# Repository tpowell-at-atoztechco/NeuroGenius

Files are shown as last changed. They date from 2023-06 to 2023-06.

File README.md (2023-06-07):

     _   _                       ____            _           
    | \ | | ___ _   _ _ __ ___  / ___| ___ _ __ (_)_   _ ___ 
    |  \| |/ _ \ | | | '__/ _ \| |  _ / _ \ '_ \| | | | / __|
    | |\  |  __/ |_| | | | (_) | |_| |  __/ | | | | |_| \__ \
    |_| \_|\___|\__,_|_|  \___/ \____|\___|_| |_|_|\__,_|___/
 
NeuroGenius - Open source, MRI imaging hardware and software (Using readily-accessible parts and operating systems, all published and documented.)

Our goal: Increasing the oligodendrocyte cell population and performi targeted remyelination through real-time functional MRI analysis for neurofeedback. Primarily as a treatment to restore functionality 
in multiple sclerosis patients and patients with other neurodegenerative diseases.

Primary Endpoints:

    1.) Providing real-time fMRI analysis using fully reproducable open source hardware and software.
    2.) Stimulated Oligodendrocyte cell population growth through secondary neurofeedback stimulation.
    3.) Successful remyeliniation on patients which can be witnessed in professional gadolinium-enhanced MRI imaging, which is universally reproducable.
    
Secondary Endpoints:

    1.) Decreased levels of cNfL levels in blood tests.
    2.) Increased evidence of oligodendrocyte stimulation in blood testing should be conducive to a strong remylenation environment.

<h1>Credits</h1>
<p>NeuroGenius is built entirely using open-source designs, including the OSI² ONE MR imager and the Homemade Liquid Nitrogen Generator.</p>
<p>Original MR Imaging design by OpenSourceImaging.org's OSI² ONE (https://www.opensourceimaging.org/2023/01/09/first-open-source-mri-scanner-presented-the-osii-one/), and is based off of their hardware designs for MRI imaging. Upgrades to their design are underway, and will be posted as they become available. For the moment, it gives us the ability to perform real-time MRI analysis, albeit somewhat low quality. Our goal is to build the technology from this point, and provide detailed documentation on how to build the MRI machine, operate the hardware and software, and build your own projects on top of it.</p>
<h1>Sitemap</h1>
<p>Helps you navigate the NeuroGenius project files. We've done our best to layout the project as best as we can, but this point of reference makes it even more user-friendly.</p>
<ul>
<li><b>Folders (/)</b>:
<ul>
<li><p><b>Concept</b>: GitHub-formatted references and guides to magnetic resonance imaging science and terminilogy, including a step-by-step guide to assemble your very own MRI machine and a liquid nitrogen generator from scratch.</p></li>
<li><p><b>Hardware</b>: Contains 3D models and circuit diagrams for building both the MRI machine and DIY Cryogenic Electrolysis system for Hydrogen Purification and Liquification.</p></li>
<li><p><b>Software</b>: Contains software for the MRI machine, which will include code for the RF amplifier, gradient power amplifier, the software to actually deliver the MRI data from raw magnetic resonance input, and the Slicer software to run comparative analysis. </p><p>Eventually, this will include a folder for NeuroGenius, which will be available as a Windows app, Apple Mac & iOS app, Android app, and a Linux app.</p>
</ul>
</li>
<li><b>Files (/)</b>:
<ul>
<li><p><b>README.md</b>: This README file</p></li>
</ul>
</li>
</ul>

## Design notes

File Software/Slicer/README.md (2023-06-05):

<h1>3D Slicer</h1>
<h2>Image computing platform</h2>
<p>3D Slicer is an open-source application designed to open and interpret MRI data, allowing you to apply patterns and create your own database of MRI files. Upon installation, one of the first things you'll see is that it's not, "designed for clinical use." With that said, it is incorporated into many similiar softwares used professionally and internationally</p><p>3D SLicer can be downloaded from <a href="https://download.slicer.org/">https://download.slicer.org/</a> for Windows, Mac OS, and Linux, completely free of charge.</p><p>For compatibility purposes, we're including a copy of the SLicer installer in this repository. All of these are current as of June 5th, 2023.</p>
<p>Slicer is built and tested on many hardware and software platforms. 3D Slicer runs on modern Windows, macOS, and a variety of Linux distributions.<p>
<h3>Operating System</h3>
<ul>
<li>Windows: Windows 10 or 11, with all recommended updates installed. Windows 10 Version 1903 (May 2019 Update) version or later is required for support of international characters (UTF-8) in filenames and text. Microsoft does not support Windows 8.1 and Windows 7 anymore and Slicer is not tested on these legacy operating system versions, but may still work.</li>
<li>macOS: macOS Big Sur (11) or later (both Intel and ARM based systems). Latest public release is recommended.</li>
<li>Linux: Ubuntu 18.04 or later<br/>
CentOS 7 or later. Latest LTS (Long-term-support) version is recommended.</li>
</ul>
<h3>Hardware</h3>
<ul>
<li>Memory: more than 4GB (8 or more is recommended). As a general rule, have 10x more memory than the amount of data that you load.</li>
<li>Display: a minimum resolution of 1024 by 768 (1280 by 1024 or better is recommended).</li>
<li>Graphics: Dedicated graphics hardware (discrete GPU) memory is recommended for fast volume rendering. GPU: Graphics must support minimum OpenGL 3.2. Integrated graphics card is sufficient for basic visualization. Discrete graphics card (such as NVidia GPU) is recommended for interactive 3D volume rendering and fast rendering of complex scenes. GPU texture memory (VRAM) should be larger than your largest dataset (e.g., working with 2GB data, get VRAM > 4GB) and check that your images fit in maximum texture dimensions of your GPU hardware. Except rendering, most calculations are performed on CPU, therefore having a faster GPU will generally not impact the overall speed of the application.</li>
<li>Some computations in 3D Slicer are multi-threaded and will benefit from multi core, multi CPU configurations.</li>
<li>Interface device: a three button mouse with scroll wheel is recommended. Pen, multi-touchscreen, touchpad, and graphic tablet are supported. All OpenVR-compatible virtual reality headsets are supported for virtual reality display.</li>
<li>Internet connection to access extensions, Python packages, online documentation, sample data sets, and tutorials.</li>
</ul>

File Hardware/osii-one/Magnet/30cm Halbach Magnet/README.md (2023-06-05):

# Permanent magnet in Halbach arrangement

Permanent magnet(B<sub>0</sub> around 48mT) MRI system. 

## System specifications
- Permanent magnet (~4000x (12x12x12)mm³ NdFeB magnets in Halbach arrangement)
- B<sub>0</sub> = 48mT
- Homogeneity (25cm, before shim) = 17.000 ppm
- Homogeneity (20cm, before shim) = 7.000 ppm
- Weight ~100kg

## Authors and acknowledgment
Design by Lukas Winter (lukas.winter@ptb.de) on the basis of O'Reilly T, et al., ISMRM 2022, #0063.
The number of magnets and radius was determined by using the open source software: https://github.com/LUMC-LowFieldMRI/HalbachOptimisation

If you find this work useful, please cite: 
O'Reilly T, Teeuwisse WU, Webb A, Three-Dimensional MRI in a homogeneous 27cm diameter Bore Halbach Array Magnet, J Magn Reson, 2019, 307:106578

O'Reilly T, Teeuwisse W, Webb A, A New Approach to Shimming Halbach Arrays Using Higher Order Halbach Array Inserts, ISMRM 2022, #0063

## License and Liability
This is an open source hardware project licensed under the CERN Open Hardware license. For more information please check the [DISCLAIMER.pdf](DISCLAIMER.pdf).

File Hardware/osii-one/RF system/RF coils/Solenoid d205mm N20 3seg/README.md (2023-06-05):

# Solenoid RF coil - 20.5cm, f=2.04Mhz

A multipurpose RF coil for low-field MRI of the OSI² ONE system. Designed to image the ACR phantom. 

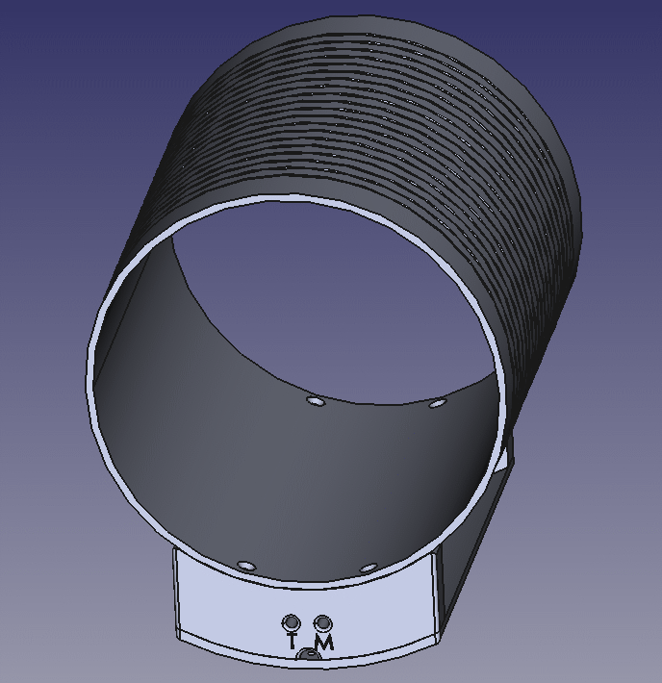
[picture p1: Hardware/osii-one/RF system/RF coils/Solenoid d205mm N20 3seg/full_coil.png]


## Specifications
- Inner diameter: 205mm
- Outer diamter: 213mm
- Solenoid length: 200mm
- Housing length: 240mm
- Number of turns: 20
- Number of segmentations: 3

## Authors and contributors

Original design by Tom O'Reilly (t.o_reilly@lumc.nl), LUMC, Leiden, Netherlands.

## (Known) builds
Name | Email | Institution 
|-----|-----|-----|
Tom O'Reilly | t.o_reilly@lumc.nl | LUMC, Leiden, Netherlands 
Lukas Winter | lukas.winter@ptb.de | Physikalisch-Technische Bundesanstalt (PTB), Berlin, Germany

## License and Liability
Please check the [DISCLAIMER.pdf](DISCLAIMER.pdf).

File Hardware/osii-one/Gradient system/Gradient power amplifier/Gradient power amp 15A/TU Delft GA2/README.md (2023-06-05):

# TU Delft GA2

Three-channel gradient power amplifier designed for a low-field (B<sub>0</sub> around 50mT) MRI system. For more information on the design, please check the [GA_DesignDoc.pdf](GA_DesignDoc.pdf).

## System specifications
- I<sub>LOAD</sub> = &#177;15A
- Duty cycle: 30% per channel
- Potentially battery powered
- V<sub>in</sub>=&#177;10V
- L=20&micro;H - 300 &micro;H (180 &micro;H)
- ESR = 0.4&ohm;, C<sub>PAR</sub> = 130 &pico;F
- t<sub>r</sub>=50 &micro;s, B=7kHz
- R<sub>SOURCE</sub>=200&ohm;
- Overload protection
- Low noise current and EMI especially between 0.5MHz...5MHz

## Authors and acknowledgment
Original design by Danny de Gans (D.H.deGans@tudelft.nl) from TU Delft, Netherlands.

## License and Liability
Please check the [DISCLAIMER.pdf](DISCLAIMER.pdf).

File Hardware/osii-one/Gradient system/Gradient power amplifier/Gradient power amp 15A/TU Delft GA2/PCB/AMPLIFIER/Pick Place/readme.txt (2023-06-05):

Instructions for assembly at Eurocircuits

Upload the zip file with the gerber files
After it has been verified open the PCB visualizer to view the PCB
Check the box "Include assembly" and select the PCBA visualizer tab
Press the button edit assembly data and Upload the BOM (Bill Of Materials)
Set the column information correctly:
Data header row:	1
Data start from row:	2
Data ends at row:	59
label the columns correctly:
Quantity, Designator and manufacturer part number
All other columns can be set to "None"

After that some components might not be recognized or should not be assembled.
Always use the exact part numbers in the search field at the bottom of the online tool
to find the correct parts. The Trough Hole transistors/FETs that are mounted onto
the heatsink should be soldered afterwards during final assembly
P2,5,8	TH	are 2 separate parts to order. MSTB2.5HC/2-GF (1923979) is the part to be selected. 1912074 is the counter part
C26,29,59,62,92,95	Do Not Assemble	, mark as Not placed in the "Supplied by:" field
R58,129,200	Do Not Assemble	, mark as Not placed in the "Supplied by:" field
Q88	Should first be mounted onto the heatsink before soldering. Mark as Not placed in the "Supplied by:" field
Q10,25,60	Should first be mounted onto the heatsink before soldering. Mark as Not placed in the "Supplied by:" field
Q13,38,63	Should first be mounted onto the heatsink before soldering. Mark as Not placed in the "Supplied by:" field
Q93	Should first be mounted onto the heatsink before soldering. Mark as Not placed in the "Supplied by:" field and "ignored"

In the manufacturers ordering process resistors and capacitors might be replaced
by "regular"parts. This is not advisable for the precise parts !!!!!!

Select the CPL tab
Upload the CPL (Component Placement List) pick and place file "EC_PickAndPlace.txt"
This file has some modified orientations to match the Eurocircuits process
delimiter:	space
data header row:	13
data start from row:	14
data ends at row:	555
The reference designator, side, center x, center y and rotation must be indentified manually
All other columns can be set to "None"
After submitting some parts need to be shifted by using the online tool "Offset Component":
P10,11,12,13
Q87,89,92,94

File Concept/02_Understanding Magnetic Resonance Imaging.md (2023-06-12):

Basic Principles of Magnetic Resonance Imaging:
Magnetic Resonance Imaging (MRI) is a non-invasive imaging technique that uses a powerful magnetic field and radio waves to generate detailed images of the body's internal structures. It is especially useful for imaging soft tissues and organs like the brain. The basic principle behind MRI involves aligning the spins of hydrogen atoms in the body using a strong magnetic field, then disturbing this alignment with a radiofrequency pulse. The subsequent relaxation of these atoms produces signals that are captured and processed to create images.

Components of an MRI Machine:
A typical MRI machine comprises of several key components: the main magnet that creates a powerful magnetic field, gradient coils that generate smaller magnetic fields for spatial encoding, a radiofrequency (RF) system that sends and receives signals, and a computer system to control these components and process the acquired data. These elements work together to create a detailed image of the desired section of the body.

Functionality of an MRI Machine:
The MRI machine works by first creating a strong magnetic field that aligns the protons in the body. The RF system then sends a radio wave to disturb this alignment. As the protons return to their original state, they emit signals that the RF system detects. These signals are processed by the computer system to create a detailed image. Different tissue types return to their original state at different rates, allowing for differentiation between them in the final image.

Understanding MRI Signals and Image Processing:
The signals received in an MRI machine are known as Free Induction Decay (FID) signals, which are then digitized and processed. Fourier transform, a mathematical technique, is used to convert these time-domain signals into frequency-domain data, allowing the spatial location of the signal source (tissue) to be determined. This is the basis for image formation in MRI.

Introduction to MRI-Driven Neurofeedback:
MRI-driven neurofeedback is a process where individuals can view and potentially alter their brain activity in real-time. By integrating this feature into the NeuroGenius software, users can gain insights into their neural activities and even attempt to modify them. This unique capability offers opportunities for self-exploration, potential therapeutic uses, and advancement in neuroscience research.

Safety Concerns in Magnetic Resonance Imaging:
Despite being a non-invasive technique, MRI involves the use of strong magnetic fields and radio waves, which necessitate certain safety precautions. These include excluding individuals with certain implants or metallic objects from undergoing an MRI scan, and ensuring that the machine is operated properly to avoid any potential harm. Safety guidelines provided by NeuroGenius and other professional bodies should always be followed.

Exploring the Future: Personal MRI with NeuroGenius:
NeuroGenius offers the intriguing possibility of personal, open-source MRI technology. By enabling individuals to build, modify, and improve upon their own MRI machine and accompanying software, NeuroGenius empowers users to explore the fascinating world of neuroimaging. This not only democratizes the technology but also spurs innovation and research in the field, paving the way for advancements in understanding the human brain.

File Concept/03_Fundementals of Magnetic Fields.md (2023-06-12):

The Physics of Magnetic Fields:
Magnetic fields are vector fields that exert forces on magnetic dipoles, such as atoms or subatomic particles like electrons and protons. The intensity and direction of these fields, measured in units of Tesla (T) in the International System of Units, can significantly influence the behavior of these particles, and this property is the basis of MRI technology.

Role of Magnetic Fields in MRI: Nuclear Magnetic Resonance:
Magnetic Resonance Imaging leverages the physics of nuclear magnetic resonance (NMR). In the presence of an external magnetic field, atomic nuclei such as hydrogen (the most abundant in the human body) exhibit magnetic properties because of their spin. The external field causes these protons to align along the direction of the field, creating two energy states. When an additional radio frequency (RF) pulse, tuned to the resonance frequency of these protons, is introduced, the protons absorb the RF energy and flip to the higher energy state. When the RF pulse is turned off, the protons relax back to their lower energy state, emitting a signal in the process. This emitted signal forms the basis of the MRI image.

Generation and Control of Magnetic Fields in MRI Systems:
MRI machines typically generate magnetic fields using superconducting coils, often composed of niobium-titanium alloy, which are cooled to cryogenic temperatures with liquid helium. The use of superconducting materials allows for high current density and thus high magnetic fields to be produced, with excellent temporal stability. Fine control of these magnetic fields is essential for accurate imaging and is accomplished through a combination of hardware design and software control.

The Impact of Magnetic Field Homogeneity and Strength on Image Quality:
The quality and clarity of an MRI image depend on the strength and homogeneity of the magnetic field. A stronger magnetic field leads to a higher signal-to-noise ratio, which improves the resolution and quality of the image. Homogeneity of the field is crucial to ensure consistent signal generation across the imaging volume, which is achieved through a process called shimming. However, higher magnetic field strengths introduce additional technical challenges and safety considerations.

Magnetic Field Gradients and Spatial Encoding:
Gradient magnetic fields are used in MRI to spatially encode the source of the NMR signals. These gradients are superimposed on the main static magnetic field, and they allow the MRI machine to localize the signal in three dimensions. This spatial encoding forms the basis for the construction of detailed, slice-by-slice images of the body's internal structures.

Biophysical Safety Considerations of MRI Magnetic Fields:
The strong magnetic fields and rapid gradient switching in MRI can have significant safety implications. The static magnetic field can attract ferromagnetic materials, leading to potential projectile hazards. Rapid switching of gradient fields can induce electrical currents in the body, causing peripheral nerve stimulation. Care must be taken to ensure that the specific absorption rate (SAR) of RF energy is within safe limits to prevent tissue heating.

Tailoring Magnetic Fields for NeuroGenius: Engineering and Design:
NeuroGenius presents unique challenges and opportunities in the design and control of magnetic fields for personal MRI use. Open-source collaboration allows for continuous innovation in creating effective magnetic field control strategies, improving homogeneity, increasing field strength, and managing safety issues. As a user-based MRI project, NeuroGenius propels further understanding and advancements in the generation and manipulation of magnetic fields for MRI applications.

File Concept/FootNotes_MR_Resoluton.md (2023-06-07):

<h1>Resolution in MR Imaging (In Common Terms)</h1>
<p>MRI resolution is typically measured in units of millimeters (mm) or micrometers (μm). It refers to the level of detail or the smallest discernible feature that can be distinguished in an MRI image.</p>
<p>In comparison to photography, where resolution is commonly expressed in terms of pixels, megapixels (MP), and gigapixels (GP), there is a fundamental difference in how resolution is quantified in MRI and digital imaging.</p>
<p>In MRI, resolution is primarily determined by the physical characteristics of the imaging system, such as the strength of the magnetic field, gradient strength, and the specific imaging sequence used. It is influenced by factors like voxel size, signal-to-noise ratio, and the inherent limitations of the MRI technology itself. The resolution is typically specified in terms of the smallest distinguishable feature size, such as the smallest anatomical structure or lesion that can be resolved.</p>
<p>On the other hand, in digital photography, resolution refers to the number of pixels in an image, often represented as megapixels (1 MP = 1 million pixels) or gigapixels (1 GP = 1 billion pixels). It represents the total number of individual picture elements that make up the image. Higher pixel counts generally allow for greater detail and the ability to enlarge or crop images without significant loss of quality.</p>
<p>It's important to note that the concept of resolution in MRI and digital imaging is not directly comparable. MRI resolution is not directly measured in pixels, as it is based on the physical properties of the imaging system and the ability to resolve fine details in the scanned anatomy. In contrast, digital imaging resolution, such as in photography, is determined by the number of pixels captured and displayed in the image.</p>
<h2>Interference and pinpoint accuracy in MR systems</h2>
<p>When it comes to MRI systems, the magnetic field strength plays a crucial role in determining the resolution and image quality. Low-field MRI systems typically operate at magnetic field strengths below 1.5 Tesla, while high-field MRI systems utilize stronger magnetic fields, often ranging from 1.5 Tesla to 3 Tesla or even higher.</p>
<p>The use of expensive magnets and superconductors in high-field MRI systems allows for the generation of a higher magnetic field, resulting in improved image resolution and quality. The higher field strength enhances the signal-to-noise ratio, enabling clearer visualization of anatomical structures and smaller pathological features.</p>
<p>With higher field strength, the pinpoint accuracy of imaging is enhanced, allowing for more precise localization and characterization of abnormalities. This can be particularly beneficial in areas such as neuroimaging, where fine details and small lesions need to be accurately identified.</p>
<p>However, it's worth noting that high-field MRI systems require specialized infrastructure, including proper shielding and cooling systems for the superconducting magnets, which can be more costly to install and maintain compared to low-field systems.</p>
<p>Overall, the choice between low-field and high-field MRI systems depends on various factors, including the specific imaging requirements, available resources, and the desired level of resolution and image quality for a particular clinical or research application.</p>
<h2>Incorporating MRI Imaging with Superconductivity</h2>
<p>One of the major barriers in producing a high-field magnetic resonance imaging machine is the cost associated with acquiring magnets that can generate a high magnetic field. Low magnetic fields product unit while high magnetic fields product unit. Run-of-the-mill rare earth magnets product

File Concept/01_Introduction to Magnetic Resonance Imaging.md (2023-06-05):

This introduction is intended to be easy to build, despite being remarkably complex in design and it's very nature. In this section, we'll attempt 
to break down what an MRI machine is, how it's used, and how it functionaly operates to capture imagery that's otherwise unobtainable. We'll also
delve into the different types of MRI machines, and dissect the exact hardware and software differences.

<h1>Concept: What is an MRI machine? (In simple terms)</h1>

An <i>MRI machine</i> is a special machine that helps doctors see inside your body to find out what's happening. It's like taking a picture, but instead 
of using light, it uses strong magnets and radio waves.

When you go inside the MRI machine, you lie down on a table that moves into a big tube-like machine. The machine has a very strong magnet inside, 
like a giant magnet. This magnet creates a powerful magnetic field around you.

Our bodies have lots of tiny particles called atoms. One of the most common atoms in our body is called hydrogen. The magnet in the MRI machine
makes the hydrogen atoms in your body act in a special way, rotating so that the MRI machine can see them.

Next, the machine sends radio waves into your body. These radio waves make the hydrogen atoms in your body vibrate. When the radio waves stop,
the hydrogen atoms go back to their normal state.

But here's the cool part: when the hydrogen atoms go back to their normal state, they release a signal. This signal is like a message that the MRI
machine can understand. The machine captures these signals and turns them into pictures.

These pictures help doctors see what's happening inside your body. They can look at your brain, your bones, your muscles, and even your organs. It
helps them find problems or see if you're healthy.

It's important to stay still during an MRI because any movement can blur the pictures. The machine may also make loud noises, but don't worry, you'll
be given earplugs or headphones to make it more comfortable.

So, an MRI machine is like a special camera that uses magnets and radio waves to take pictures of the inside of your body. It helps doctors see
what's going on and make sure you're healthy.

<h1>Advanced concepts: How does an MRI machine actually work?</h1>

To gain a deeper understanding of how an MRI machine functions, we will explore its technical aspects, including gradient magnets and their role in adjusting imaging resolution relative to Earth's magnetic field. By examining these intricacies, we can appreciate the sophisticated nature of MRI technology.

<h2>Magnetic Fields and Precession:</h2>
Central to an MRI machine's operation is a powerful magnet that generates a homogeneous magnetic field encompassing the scanning area. This field aligns the intrinsic magnetic moments of hydrogen nuclei within the body, creating a net magnetization.

In addition to the primary magnet, MRI machines incorporate gradient magnets. These specialized magnets produce additional magnetic fields that vary spatially, allowing for precise localization of signals during the imaging process.

<h2>Gradient Magnets and Spatial Encoding:</h2>
By generating gradients in the magnetic field, the gradient magnets help establish spatial coordinates within the body. This spatial encoding enables differentiation between signals originating from various locations. The gradients influence the resonance frequencies of hydrogen nuclei in different regions, thereby enabling the precise determination of their origin.

<h2>Radiofrequency Excitation and Signal Reception:</h2>
After spatial encoding, the MRI machine employs radiofrequency (RF) coils to interact with the aligned hydrogen nuclei. RF pulses, tuned to a specific frequency, excite the nuclei, causing them to transition from their low-energy state to a higher-energy state.

Upon termination of the RF pulses, the hydrogen nuclei return to their low-energy state, releasing energy in the form of radiofrequency signals. The RF coils, acting as both transmitters and receivers, capture these signals, which contain information about the tissues' local environment.

<h2>Gradient Encoding and Image Reconstruction:</h2>
The gradient magnets play another crucial role in image reconstruction. By applying gradients during the signal acquisition process, the MRI machine encodes spatial information within the received signals. These gradient-encoded signals, along with timing and intensity parameters, are used to reconstruct the final images.

To account for Earth's magnetic field variations and optimize imaging resolution, the gradient magnets can be calibrated accordingly. This adjustment helps compensate for spatial distortions caused by the Earth's magnetic field, ensuring accurate and precise imaging.

<h2>Contrast and Tissue Differentiation:</h2>
MRI technology offers remarkable contrast between different tissues, enabling detailed differentiation. This contrast arises due to variations in the relaxation times of hydrogen nuclei within different tissue types.

Tissues with different properties, such as water-rich regions versus fat-rich regions, exhibit distinct relaxation times. By manipulating pulse sequences and timing parameters, MRI machines can exploit these differences to generate contrasting signals and enhance tissue differentiation.

<h2>Coils as the aperature and the lens</h2>

Coils play a vital role in the MRI imaging process. Firstly, specialized radiofrequency (RF) coils act as transmitters, emitting precisely tuned RF pulses into the body. These pulses interact with the aligned hydrogen nuclei, exciting them and causing a temporary disturbance in their magnetic alignment. This excitation is crucial for generating the signals that will later be used to construct the images.

Simultaneously, the same RF coils function as receivers, capturing the signals emitted by the hydrogen nuclei as they return to their original alignment. These signals, containing valuable information about the local tissue environment, are then transmitted to the computer system for further processing.

The computer system analyzes the received signals and applies sophisticated mathematical algorithms to reconstruct the final images. This image reconstruction process involves intricate computations that incorporate the encoded spatial information obtained through the gradient magnets. By precisely manipulating the signals and their spatial coordinates, the computer system generates detailed images that depict the internal structures of the body.

The use of coils in both transmitting RF pulses and receiving signals is a remarkable example of how a single component can serve multiple purposes. This dual functionality not only ensures the efficient utilization of resources but also contributes to the overall accuracy and quality of the resulting images.

By understanding the intricate interplay between coils, magnetic fields, gradients, and signal processing, we gain a deeper appreciation for the complexity of MRI technology. The ability of coils to both generate and receive electromagnetic radiation allows MRI machines to capture detailed and informative images of the body's internal structures.

MRI technology continues to advance, with ongoing research focused on enhancing image quality, reducing scanning times, and expanding the range of applications. The contributions made by coils in this process underscore their significance in the development and refinement of MRI machines, ultimately leading to improved diagnostics, treatment planning, and medical care.

In summary, the use of coils as both transmitters and receivers of electromagnetic radiation, coupled with sophisticated image reconstruction techniques, forms the foundation of MRI imaging. The synergy between these components enables the creation of detailed images that aid in medical diagnosis and contribute to advancements in healthcare.

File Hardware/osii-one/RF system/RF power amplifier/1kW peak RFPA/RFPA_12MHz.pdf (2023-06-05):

# 12MHz Pulse Amplifier

Gain @ 4MHz | 54.3 dB
Bandwidth | 500kHz – 12MHz
Enable | 5V 1%
Max load power | 1 kW
Max duty cycle | 10 %
Max pulse duration | 20 ms
Rout @ 4MHz | 48.2 Ω
Rin | 50 Ω
Blanking delay | ≤500 ns

Description:

This class A amplifier can deliver 1kW (60 dBm) pulsed power into a 50Ω load with a maximum duty cycle of 10%. Pulse power is delivered from buffer capacitors that recharge during blanking with 10% of the current that the amplifier requires. The capacitor voltage is made visible at the front of the amplifier. To prevent amplitude droop this buffered voltage is stabilized before the amplifier. The 10% recharge current effectively limits the duty cycle since the supply voltage will drop when the duty cycle is more than 10%.

The TTL enable signal controls the gating of the pre-amplifier and the power supply of the power amplifier simultaneously. Also the level of the enable signal directly controls the voltage of the linear regulator. Therefore it is important to use 5.0V as the enable voltage.

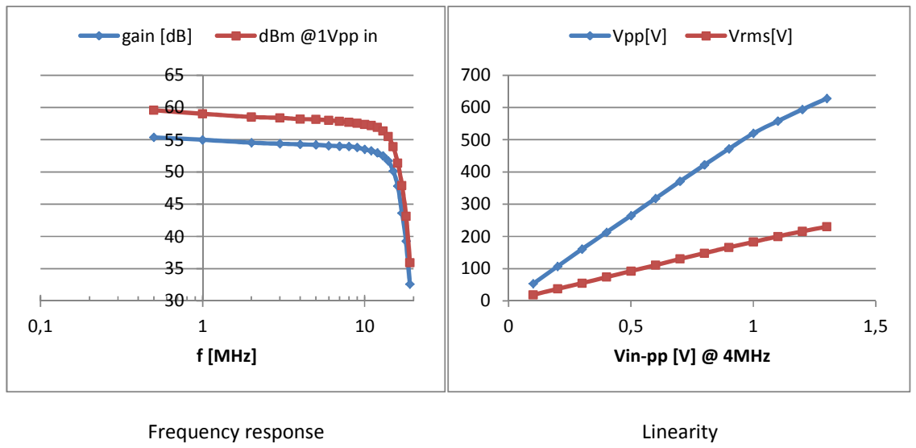
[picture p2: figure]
Frequency response; Linearity; f [MHz]; gain [dB]; dBm @1Vpp in; Vin-pp [V] @ 4MHz; Vpp[V]; Vrms[V]
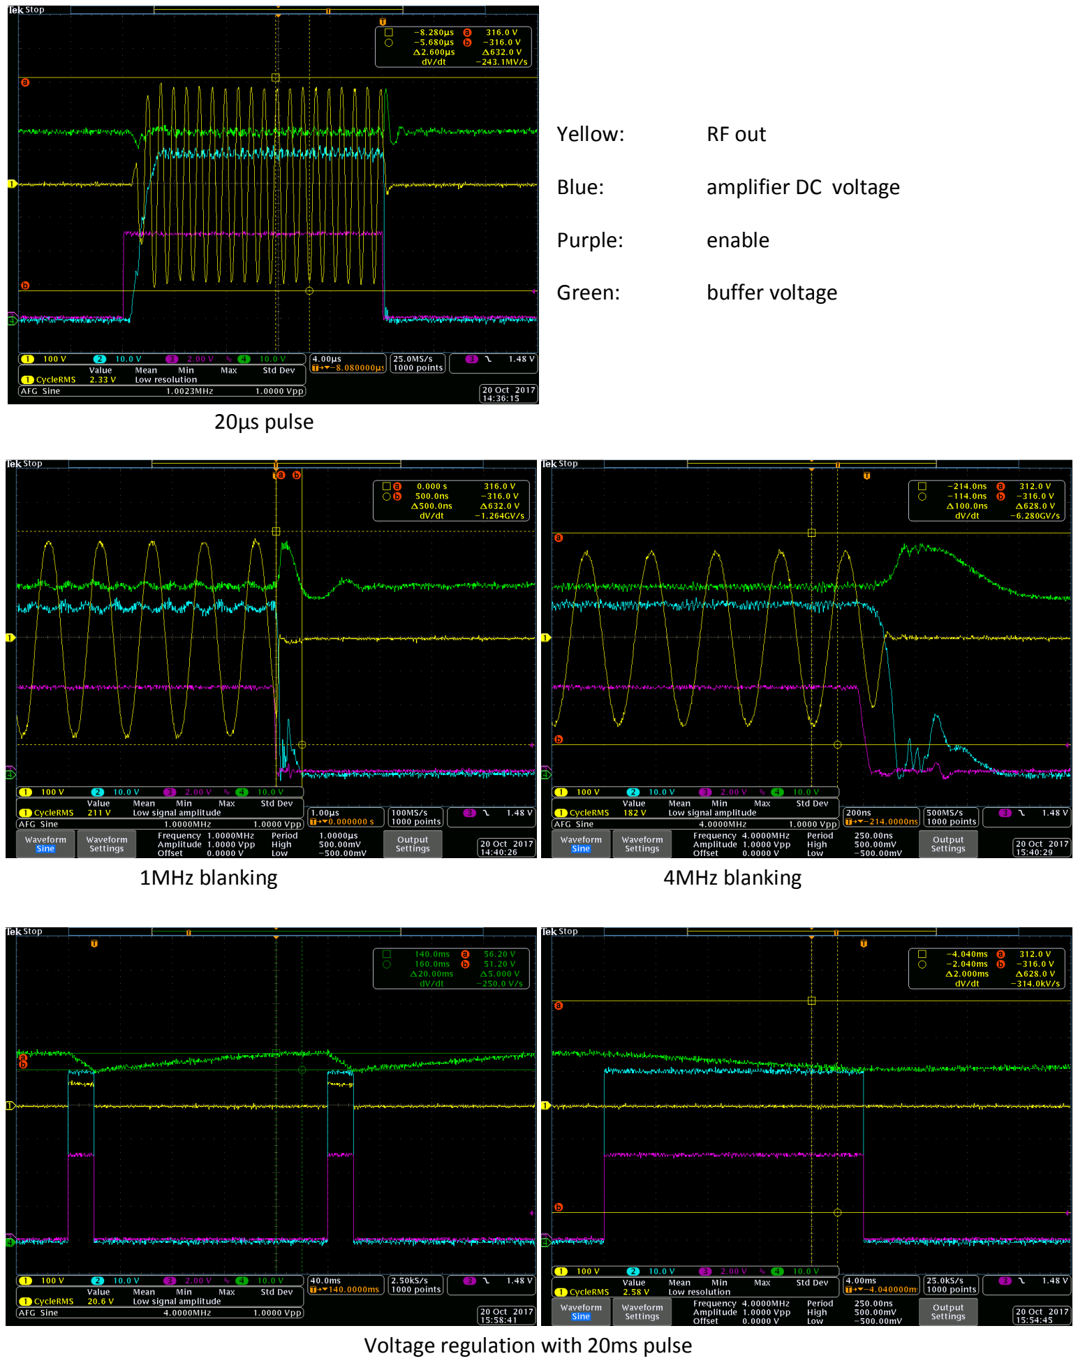
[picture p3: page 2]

Yellow: | RF out
Blue: | amplifier DC voltage
Purple: | enable
Green: | buffer voltage

20µs pulse

1MHz blanking | 4MHz blanking

Voltage regulation with 20ms pulse

There is no overload protection present, so care must be taken that

- the amplifier is loaded with 50 Ω
- input signals between 0.5 – 12MHz are used
- output power does not exceed 1kW
- enable signal of 5.0V is used

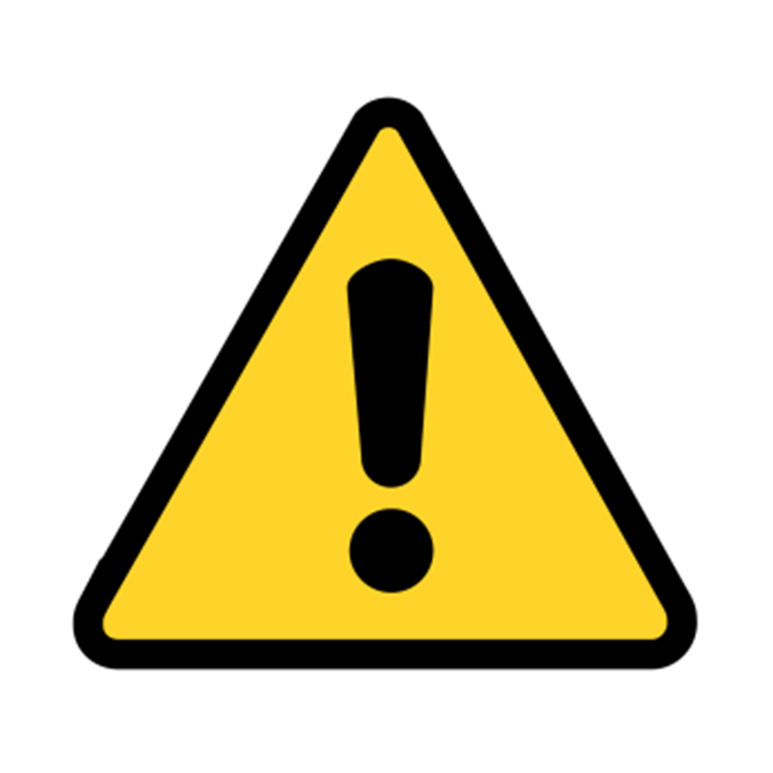
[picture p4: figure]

Future ideas:

- Enable the power supply before the RF starts to let it settle first. Disable simultaneously
- Monitor temperature, VSWR, output power + alarms
- Create a digital buffer circuit that guarantees the correct enable level .
- Band filter for the RF input signal.

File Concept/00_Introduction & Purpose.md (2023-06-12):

Overview of NeuroGenius:
NeuroGenius is an innovative open-source project that provides an accessible platform for both enthusiasts and professionals to build their own Magnetic Resonance Imaging (MRI) machine. It is based on the principles of community learning, creativity, and openness, striving to democratize advanced medical imaging technology. The main aim of the NeuroGenius project is to enable users to have a better understanding of neuroimaging, and provide a platform for exploration and innovation in this field.

What Makes NeuroGenius Unique:
Unlike conventional MRI machines, NeuroGenius is designed to be user-friendly, cost-effective, and customizable. The open-source nature of the project allows for continuous improvements and additions by its user community. With its cutting-edge software, NeuroGenius also supports MRI-driven neurofeedback, allowing users to understand their brain function in real-time and potentially modify their brain activity for therapeutic purposes.

Building Your NeuroGenius Machine:
Building your own NeuroGenius machine is a journey of exploration and learning. Detailed assembly instructions and a list of necessary components are available on the NeuroGenius project website. The basic requirements include a stable power supply, magnet, radio frequency (RF) system, gradient system, and a computer for control and data processing. While assembly might seem challenging, the support of an active online community and the detailed guides ensure that the process is accessible even to those without a technical background.

Understanding the NeuroGenius Software:
The NeuroGenius software is a key component of the project. It controls the MRI machine and processes the captured data, making it possible to generate and visualize complex images of the brain. The software also supports a range of advanced features, including the possibility for real-time neurofeedback. As an open-source project, users are encouraged to modify and improve upon the software, adding new features and optimizing existing ones.

Neurofeedback and Its Applications in NeuroGenius:
Neurofeedback is a process by which individuals can visualize and potentially modify their brain activity in real-time. By integrating this feature into the NeuroGenius software, users can use their own MRI data to study their brain function and even attempt to modify their neural activities. This opens up a plethora of opportunities for self-exploration, therapy, and neuroscience research.

Health and Safety Considerations:
While NeuroGenius is designed to be user-friendly and accessible, it's important to remember that MRI technology involves strong magnetic fields and RF signals. Therefore, it's crucial to ensure safe assembly and operation. The NeuroGenius community provides comprehensive safety guidelines and protocols that users must follow.

The Future of Open-Source MRI Technology with NeuroGenius:
NeuroGenius heralds a new era in the world of medical imaging technology, breaking down barriers of cost and accessibility. The future of the project depends on the continued contribution and innovation of its user community. By encouraging active participation, NeuroGenius aims to constantly improve and diversify the capabilities of open-source MRI technology, leading to widespread implications for medical research, therapy, and neuroscience.

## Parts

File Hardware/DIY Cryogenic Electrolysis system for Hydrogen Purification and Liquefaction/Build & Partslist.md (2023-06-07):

<h1>Build a Cryogenic Electrolysis system for Hydrogen Purification and Liquefaction</h1>
<p>Follow this guide to create an efficient liquid hydrogen generator! (Based on the <a href="https://www.instructables.com/Homemade-liquid-nitrogen-generator/">Instructable</a> by Imsmooth.)</p>
<h2>Parts list:</h2>
<ul>
<li><p><b>Appropriate container</b>: Use an appropriate container to efficiently store your freshly harvested liquid nitrogen. A simple stainless steel vacuum bottle will suffice, although more specialized containers like the Thermo Scientific Thermo-Flask™ Benchtop Liquid Nitrogen Containers exist and can be simply modified to contain freshly-extracted liquid nitrogen.</p><p>Storing liquid nitrogen at artificially higher atmospheric pressure can simplify the storage process and increase its stability. By maintaining a higher pressure, such as in a pressurized container, the boiling point of liquid nitrogen can be elevated, allowing it to remain in its liquid state for longer periods. This can facilitate easier handling, reduce the rate of evaporation, and minimize the need for frequent replenishment. However, it is crucial to ensure proper safety measures are in place when working with pressurized containers to prevent any potential hazards.</p></li>
<li><p><b>Compressor (Suggested RIX oil-free SA-3E)</b>: This is the most expensive component. We're using a RIX oil-free SA-3E. This delivers 3 SCFM @ 3500psi (230 ATM). I modified the motor and pulleys to deliver 4 SCFM. A higher flow gives you a faster cool-down and production rate. The high pressure allows you to have a larger temperature drop when you throttle the gas to a lower pressure. You can use a regular refrigerator compressor, but you will be waiting a long time to drop 400 degrees Fahrenheit from the ambient temperature to -320F if you only have 40 ATM of pressure.</p></li>
<li><p><b>Scrubber</b>: You can make this components out of PVC pipe. We used 4" PCV, along with multiple layers of filters and screens. You need to get the correct fittings to get to a pipe size that you can then attach to your compressor. The scrubber uses a material called zeolite, or molecular sieve. We specifically used 13x molecular sieve and added some 4A sieve material that had a color indicator added so I know when it has reached saturation. You determine the size of the scrubber based on your flow rate. If you want 3-4 SCFM then you need about 10-15lbs of the material and size the scrubber based on this.</p><p>Purchase links:</p>
<ul>
<li><p><b>Zeolite</b>: Naturally occurring or man-made, with finely porous material with holes that are angstroms in size and bind with CO2 and water, which enter and bind with the pores, letting the other gases, like O2 and N2 pass through. The color-indicator will change from light blue to gray when the material can not adsorb any more water. The material is regenerated by heating to 350F, driving off the CO2 and water. Purchase on Amazon: <a href="https://www.amazon.com/dp/B09XTWYG6S/ref=twister_B0BHNPZZ9Y?_encoding=UTF8&psc=1">HFS (R) Molecular Sieve Zeolite 8X12 Mesh (5LB, 4A)</a>.</p></li>
<li><p><b>200-micron screening</b>: Used to seperate different levels of zeolite for improved filteration. This screening holds the 10 lbs of material in place and prevents it from getting sucked into the compressor, but still allows for air-flow. Purchase on Amazon: <a href="https://www.amazon.com/TIMESETL-Stainless-Steel-Woven-Wire/dp/B081QB3BLF">TIMESETL 304 Stainless Steel Woven Wire 200 Mesh - 12"X 40" Filter Screen Sheet Filtration Cloth</a>.</p></li>
<li><p><b></b>: </p></li>
<li><p><b></b>: </p></li>
<li><p><b></b>: </p></li>
</ul>
</li>
<li><p><b></b>: </p></li>
</ul>

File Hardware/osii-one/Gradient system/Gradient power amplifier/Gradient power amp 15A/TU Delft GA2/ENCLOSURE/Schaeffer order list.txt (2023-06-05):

Pos. 	Quantity 	Item 									Unit price	Amount
10 		1 			Front panel:GND.fpd						27.54 € 	27.54 €
					Width: 200.00mm, Height: 43.00mm,
					Thickness: 2.00mm, Material: Aluminum
					raw, Color: Natural

20 		1 			Front panel:cover.fpd					29.13 € 	29.13 €
					Width: 200.00mm, Height: 184.00mm,
					Thickness: 2.00mm, Material: Perspex,
					Color: Clear

30 		1 			Front panel:strip1M4.fpd				10.02 € 	10.02 €
					Width: 10.00mm, Height: 46.00mm,
					Thickness: 2.00mm, Material: Aluminum
					raw, Color: Natural

40 		3 			Front panel:strip3.fpd					11.95 € 	35.85 €
					Width: 20.00mm, Height: 111.00mm,
					Thickness: 2.00mm, Material: Aluminum
					raw, Color: Natural

50 		1 			Front panel:Bottom.fpd					82.65 € 	82.65 €
					Width: 430.00mm, Height: 266.90mm,
					Thickness: 3.00mm, Material: Aluminum
					raw, Color: Natural

60 		1 			Front panel:Vpos.fpd					17.96 €		17.96 €
					Width: 160.00mm, Height: 18.00mm,
					Thickness: 2.00mm, Material: Aluminum
					raw, Color: Natural

70 		1 			Front panel:Front.fpd					134.43 € 	134.43 €
					Width: 426.70mm, Height: 128.40mm,
					Thickness: 3.00mm, Material: Aluminum
					anodized, Color: Natural

80 		1 			Front panel:back.fpd					101.80 € 	101.80 €
					Width: 431,35mm, Height: 130,50mm,
					Thickness: 3,00mm, Material: Aluminum
					anodized, Color: Natural

90 		3 			Front panel:HeatSpreader.fpd			11.79 €		35.37 €
					Width: 48,00mm, Height: 48,00mm,
					Thickness: 1,50mm, Material: Aluminum
					raw, Color: Natural

100 	3 			Front panel:strip2.fpd					10.57 € 	31.71 €
					Width: 12,00mm, Height: 66,00mm,
					Thickness: 2,00mm, Material: Aluminum
					raw, Color: Natural

110 	1 			Front panel:Vneg.fpd					20.82 €		20.82 €
					Width: 180,00mm, Height: 18,00mm,
					Thickness: 2,00mm, Material: Aluminum
					raw, Color: Natural

120 	2 			Front panel:strip1M5.fpd				10.04 €		20.08 €
					Width: 10,00mm, Height: 46,00mm,
					Thickness: 2,00mm, Material: Aluminum
					raw, Color: Natural

In shopping cart: 					547.36 €
Expedite fee:No surcharge 			0.00 €
Shipping charges (estimated):		5.95 €

Subtotal: 							553.31 €

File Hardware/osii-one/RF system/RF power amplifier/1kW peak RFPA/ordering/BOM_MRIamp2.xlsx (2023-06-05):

Designator | Footprint | Value | Farnell | Quantity | Mouser |  | Farnell | 2 | pcb's | 1pcb
C1, C2, C3, C4, C5, C6, C7, C8, C9, C10, C11, C12, C14, C15, C23, C24, C25, C27, C28, C30, C31, C32, C33, C35, C36, C38, C39, C41, C43, C44, C55, C56, C58, C59, C61, C62, C65, C66 | SM/C_0805 | 0.1uF 100V X7R | 2470440 | 38 |  |  | 2470440 | 76 |  | 38
C13, C64 | SM/C_0805 | 68pF 100V NP0 | 1759274 | 2 |  |  | 1759274 | 4 |  | 2
C16, C17, C143, C144 | SMD/C_1111 | 470p VJ1111D471JXLAJ | 2420162 | 4 |  |  | 2420162 | 8 |  | 4
C63 | SM/C_0805 | 47n 50V X7R | 1856489 | 1 |  |  | 1856489 | 2 |  | 1
C18, C19, C20 | SM/C_0805 | 1nF 200V X7R | 1740687 | 3 |  |  | 1740687 | 6 |  | 3
C21, C22, C142 | SM/C_0805 | DNA | 1740687 | 3 |  |  | 1740687 | 6 |  | 3
C26, C29, C37, C40, C45, C46, C47, C48, C49, C50, C51, C52, C53, C54, C126, C140 | SM/C_1210 | 10uF 25V X7R | 1828840 | 16 |  |  | 1828840 | 32 |  | 16
C34 | SM/C_0805 | 4n7 50V NP0 | 8820058 | 1 |  |  | 8820058 | 2 |  | 1
C42, C141, C-R51 | SM/C_0805 | 10p 50V NP0 | 2497005 | 3 |  |  | 2497005 | 6 |  | 3
C57 | SM/C_1206 | 5p6 / 500V NP0 | 1301968 | 1 |  |  | 1301968 | 2 |  | 1
C60 | SM/C_0805 | 270p / 100V NP0 | 2332698 | 1 |  |  | 2332698 | 2 |  | 1
CT1 | CT | CT |  | 1 | 623-2661102002 |  |  |  |  | 1
D1, D8, D10 | ONSC-SOD-523-2-502-01_V | BAT54XV2T5G | 2322476 | 3 |  |  | 2322476 | 6 |  | 3
D2, D4, D5, D6, D7, D9 | ONSC-SOT-323-3-419-04_V | BAV99WT1G | 1081212 | 6 |  |  | 1081212 | 12 |  | 6
D3 | SM/DO214AC_12 | ES1C | 2453261 | 1 |  |  | 2453261 | 2 |  | 1
FB1, FB2, FB3 | MURA-BLM21-B40-CHIP-2_V1 | BLM21PG300SN1B | 1515662 | 3 |  |  | 1515662 | 6 |  | 3
J1, J3 | BUSHING_M4 | 7460307 | 1821272 | 2 |  |  | 1821272 | 4 |  | 2
J2, J4 | SMA-Grotere-Gaten | 132134 | 2112465 | 2 |  |  | 2112465 | 4 |  | 2
J5 | BNC_Danny | R141426161 | 4195115 | 1 |  |  | 4195115 | 2 |  | 1
P1 | POLCON.100/VH/TM1SQS/W.300/6 | Header 6 | 588611 | 1 |  |  | 588611 | 2 |  | 1
P2, P3, P4 | POLCON.100/VH/TM1SQS/W.300/4 | HEADER 4 | 588593 | 3 |  |  | 588593 | 6 |  | 3
P5 | megaheader | RFin |  | 1 |  |  |  |  |  | 1
Q1, Q3, Q4, Q6, Q7, Q8 | ONSC-TO-225-3-77-09 | BD139 | 1015770 | 6 |  |  | 1015770 | 12 |  | 6
Q2 | TO247AA | IXTH90P10P |  | 1 | 747-IXTH90P10P |  |  |  |  | 1
Q5 | SO8_N | BSC340N08NS3 | 2212853 | 1 |  |  | 2212853 | 2 |  | 1
Q9, Q10 | ONSC-TO-225-3-77-09 | BD140 | 2341704 | 2 |  |  | 2341704 | 4 |  | 2
Q11, Q12, Q13, Q14, Q15, Q16 | FAIR-SOT23-3_V | FDV301N | 9845011 | 6 |  |  | 9845011 | 12 |  | 6
R1, R15, R18, R25, R65, R66, R70, R71, R73, R74, R85 | SM/R_0805 | 4k7 | 2447672 | 12 |  |  | 2447672 | 24 |  | 12
R2 | SM/R_1210 | 330R/0.5W | 2324053 | 1 |  |  | 2324053 | 2 |  | 1
R3, R4, R5, R6, R7, R8, R9, R10, R11, R12 | SMD/R_2512 | 2R2 | 2476359 | 10 |  |  | 2476359 | 20 |  | 10
R13, R14, R17 | SM/R_0805 | 120R | 2447561 | 3 |  |  | 2447561 | 6 |  | 3
R16 | SMD/R_2512 | 4k7/1W | 1265213 | 1 |  |  | 1265213 | 2 |  | 1
R19 | SM/R_1206 | 120R | 1100167 | 1 |  |  | 1100167 | 2 |  | 1
R20 | SM/R_1210 | 510R/0.5W | 2380767 | 1 |  |  | 2380767 | 2 |  | 1
R21 | SMD/R_2512 | 22R | 1265187 | 1 |  |  | 1265187 | 2 |  | 1
R22, R58, R59, R62 | SM/R_1210 | 220R/0.5W | 2324036 | 4 |  |  | 2324036 | 8 |  | 4
R23, R31, R32, R33, R36, R50, R52, R55, R56, R60, R79, R81, R82, R87, R93 | SM/R_0805 | 2R2 | 2074326 | 15 |  |  | 2074326 | 30 |  | 15
R24, R26 | AX/1.000X.225/.034 | 270R | 1738681 | 2 |  |  | 1738681 | 4 |  | 2
R27, R28, R51, R57 | SM/R_0805 | 470R | 2074468 | 4 |  |  | 2074468 | 8 |  | 4
R29, R30, R34, R37, R40, R41, R43, R44, R61, R63, R64, R69, R72, R75, R78 | SM/R_0805 | 39R | 2074459 | 15 |  |  | 2074459 | 30 |  | 15
R35, R42, R47, R67, R76, R77 | SM/C_1206 | 220R | 2447486 | 6 |  |  | 2447486 | 12 |  | 6
R38, R39, R53, R54, R90, R91, R92, R95 | SM/R_0805 | 10k | 2447553 | 8 |  |  | 2447553 | 16 |  | 8
R45, R46, R48, R49, R84 | SM/C_1206 | 100R | 2447454 | 5 |  |  | 2447454 | 10 |  | 5
R80 | AX/1.000X.225/.034 | 10k | 1738702 | 1 |  |  | 1738702 | 2 |  | 1
R83 | AX/1.000X.225/.034 | 10R | 1357898 | 1 |  |  | 1357898 | 2 |  | 1
R86 | AX/.550X.150/.034 | 200R | 9340149 | 1 |  |  | 9340149 | 2 |  | 1
R88, R97 | SM/R_0805 | 110k | 2447557 | 2 |  |  | 2447557 | 4 |  | 2
R89 | SM/R_0805 | 470R | 2447662 | 1 |  |  | 2447662 | 2 |  | 1
R94 | SM/R_0805 | 1k | ? | 1 |  |  | ? | 2 |  | 1
R68 | SM/R_0805 | 1M | 2447596 | 1 |  |  | 2447596 | 2 |  | 1
R96 | SM/R_0805 | 6k8 | 2447711 | 1 |  |  | 2447711 | 2 |  | 1
TR1 | PCBComponent_1 | 1:1:4:4 |  | 6 | 623-2661102002 |  |  |  |  | 1
U1 | ADI-R-8_L | AD8017ARZ | 9425705 | 1 |  |  | 9425705 | 2 |  | 1
U2 | ADI-R-8_M | AD8021ARZ | 9426000 | 1 |  |  | 9426000 | 2 |  | 1
U3, U5 | D0014A_N | SN74HC02D | 9590900 | 2 |  |  | 9590900 | 4 |  | 2
U4 | D0014A_L | SN74AHCT132D | 1739982 | 1 |  |  | 1739982 | 2 |  | 1
U6 | ADI-R-8_M | AD822ARZ | 9994351 | 1 |  |  | 9994351 | 2 |  | 1
U7 | ADI-R-8_L | AD820ARZ | 9426469 | 1 |  |  | 9426469 | 2 |  | 1
U8 | DBZ0003A_N | LM4040CIM3-2.5 | 1468840 | 1 |  |  | 1468840 | 2 |  | 1
VR1, VR2 | VRES38 | 10k | 9352651 | 2 |  |  | 9352651 | 4 |  | 2
XF1 | LFUS-154_V | 0154010.DR | 1817192 | 1 |  |  | 1817192 | 2 |  | 1
C-R28 |  | 4p7 | 2332774 | 1 |  |  | 2332774 | 2 |  | 1
RF mosfet, digi-key |  | BLF188XRU |  | 1 |  | 568-10993-ND
C trafo primair mouser/digi-key |  | CC1812JKNPOCBN152 |  | 2 | 603-CC812JKNPOCBN152 | 311-4547-1-ND
DNA = Do Not Assemble

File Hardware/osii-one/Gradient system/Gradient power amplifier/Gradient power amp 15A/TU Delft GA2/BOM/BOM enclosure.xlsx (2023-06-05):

description | MPN | Farnell | RS | amount | Digi key | reichelt | conrad | mouser
EuropacPRO Schroff Chassis, 3U, 295mm Depth | 24563133 |  | 454-9644 | 1
Arcolectric DPST Latching Rocker Switch Panel | C1350AAAAB |  | 282-8305 | 1
61 Material Round Cable Core Z=190 OHM @100MHz | 2661102002 |  |  | 2 |  |  |  | 623-2661102002
GDT, 2051 Series, 90 V, 2 Terminal SMD, 2 kA, 600 V | 2051-09-SM-RPLF |  | 733-4965 | 6
PCB contact strip for GDT | RE1010 |  | 808-8304 | 1
Relay | V23134J1052D642 |  |  | 2 |  |  |  | 655-V23134J1052D642
screw terminal | 1912074 |  |  | 3 |  |  |  | 651-1912074
MIL panel mount connector | N/MS3102A22-22P |  | 546-9779 | 1
MIL cable connector R/A | N/MS3108B22-22S |  | 547-0088 | 1
MIL back shell | N/MS3057-12A |  | 546-9993 | 1
BNC panel mount D hole 9.8x8.7 | 13-25 | 1169699 |  | 6
Banana Test Connector, 4mm, Receptacle, Panel Mount | 930147000 | 1176436 |  | 1
Analogue Panel Meter, DC Voltage, 0V to 15V, 44 mm, 44 mm | SD506/0-15V | 4434079 |  | 2
10mF 63V 10.8A 17mR | ALS30A103DE063 | 1572893 | 381-9100 | 4
LED | MC19031003 | 1105240 |  | 3
fuse holder | MC002807 | 2901459 |  | 2
fuse | MCATP-L-E 20A | 1569160 |  | 2
Coaxial Cable Assembly, 90° MCX Plug to 90° MCX Plug, RG178, 50 ohm, 1 m, White | 415-0015-M1.0 | 2833454 |  | 3
250 V, 40 A, Single, TO-220AC, 2 Pins, 970 mV | MBR40250G | 2317431 |  | 2
Ferrite Bead, Tubular, 108 ohm, WE-SAFB Series, -108 ohm, ± 25% | 74270020 | 2894691 |  | 6
TO220 insulator pad plus shoulder washer | MK3306/TG | 522636 | 712-8225 | 2
capacitor bracket | V3 |  |  | 4 | 399-11543-ND
cover plate | 24560-080 |  |  | 1 | 1439-1175-ND
heatsink | LAV 6200 24V |  |  | 1 |  | LAV 6200 24V
graphite paste | WLPK 10 | 2481093 |  | 1
thermal pad | SP2000-0.015-00-00-150X150 | 681131 | 468-2319 | 0.33
hook up wire RED | WI-M-10-25-2 |  |  | 1 |  |  |  | 548-WI-M-10-25-2
hook up wire BLK | WI-M-10-25-0 |  |  | 1 |  |  |  | 548-WI-M-10-25-0
hook up wire BLUE | WI-M-10-25-6 |  |  | 1 |  |  |  | 548-WI-M-10-25-6
battery 12V 22Ah | LC-XC1222P |  |  | 2 |  | ~~LC-XC 1222P~~
charger 6,12,24V | 1001-0014-UK |  | 800-3057 | 1
spacer 8mm Nylon | 971080365 | 2988178 | 184-1912 | 5
push button 16mm IP65 Vandal Resistant Switch SPST, 701880 TRU components | GQ16F-10E/J/G/12V |  |  | 1 |  |  | 701880
shoulder washer | 7721-8PPSG | 1838837 |  | 6
spade 9.53x1.22mm faston 10-7 AWG | 280755-4 |  | 745-4776 | 4
spade 6.35x0.81mm faston 18-14 AWG | 42281-1 | 3226676 |  | 4 |  |  |  | 571-422811-CT
PIDG FASTON 250 Series, Female Quick Disconnect, 6.35mm x 0.81mm | 640907-2 | 2311754 |  | 4 |  |  |  | 571-6409071
TVS diode 37.1V | P6KE39CA | 9885498 |  | 2
standoff 15mm M4 | 05.14.153 | 1466807 |  | 2
standoff 21mm M3 | 971210324 | 2988268 |  | 2
cable 4 wire | PP000277 | 2440061 |  | 1m
cable 2 core | 0028202 | 1204310 |  | 1m
wire to board connector 2 pin | 3-640442-2 | 1098708 |  | 1
wire to board connector 4 pin | 3-640442-4 | 1098712 |  | 3
ground lug terminal M3 | D01499 | 1733431 |  | 1
 |  | €334 | €195 |  | €65 | €85 | €15 | €200 | €894
 |  |  |  |  |  | zonder accu

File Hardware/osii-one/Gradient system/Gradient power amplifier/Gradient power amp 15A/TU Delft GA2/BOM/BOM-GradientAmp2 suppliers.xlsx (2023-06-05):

 | Gradient Amplifier 2 |  |  |  |  |  | #PCBs | 1
Layer | Quantity | Designator | Comment | Footprint | MPN | Pin Info | RS | MOUSER | Digi-Key | Farnell | Quant
Top | 1 | P13 | Header 2 | DG-MTA-2 | 640456-2 | MTA |  |  |  | 588570 | 1
Top | 2 | C103, C104 | 10uF | SMD/C_0805 | 08053D106KAT2A | X5R, 25V, 10% |  |  |  | 1867958 | 2
Top | 2 | D31, D32 | PMEG6010CEJ,115 | NXP-SOD323F_V | PMEG6010CEJ,115 | 60V, 1A, low Vf |  |  |  | 2575120 | 2
Top | 2 | Q87, Q89 | FQD7P20 | DPAK 2 | FQD7P20TM | 200V, 5.7A | 671-1034 |  |  |  | 2
Top | 2 | Q92, Q94 | FDD7N20 | DPAK 2 | FDD7N20TM | 200V, 5A |  |  |  | 2453852 | 2
Top | 2 | R226, R227 | 11k | SMD/RF_0805 | CRCW080511K0FKEA | 1%, 125mW, thick film | 679-0831 |  |  |  | 2
Top | 2 | R245, R246 | 5M6 | SMD/RF_0805 | RC0805FR-075M6L | 1%, 125mW, thick film |  | 603-RC0805FR-075M6L | 13-RC0805FR-075M6LCT-ND |  | 2
Top | 3 | C14, C47, C80 | 470pF | SMD/C_0805 | 08051A471JAT2A | NP0, 100V, 5% |  |  |  | 499195 | 3
Top | 3 | C29, C62, C95 | DNA | SMD/C_0805 |  | X7R, 50V, 10%
Top | 3 | P2, P5, P8 | Header 2 | MSTB2.5HC/2-GF | 1923979 + 1912074 | 16A, screw flange, 5mm |  | 651-1923979 |  |  | 3
Top | 3 | P10, P11, P12 | HEADER 4 | DG-MTA-4 | 640456-4 | MTA |  |  |  | 588593 | 1
Top | 3 | Q23, Q48, Q73 | BSS84L | SOT-23_L | (S)BSS84LT1G | 50V, 130mA |  |  |  | 2845396 | 3
Top | 3 | R29, R100, R171 | 82k | SMD/RF_0805 | RC0805FR-0782KL | 1%, 125mW, thick film |  |  |  | 9237860 | 3
Top | 3 | R30, R101, R172 | 1k15 | SMD/RF_0805 | RP73PF2A1K15BTDF | 0.1%, 250mW, 25ppm/K, thin film |  |  |  | 2117168 | 3
Top | 3 | R67, R138, R209 | 13 | SMD/RF_0805 | CRCW080513R0FKEA | 1%, 125mW, 100ppm/K, thick film |  |  |  | 2138741 | 3
Top | 3 | R69, R140, R211 | 360 | SMD/RF_0805 | CRCW0805360RFKEA | 1%, 125mW, 100ppm/K, thick film |  |  |  | 1180260 | 3
Top | 3 | U1, U10, U19 | ADA4084-2 | ADI-R-8_N | ADA4084-2ARZ | +-15V, 3.9nV/rtHz |  | 584-ADA4084-2ARZ |  |  | 3
Top | 4 | R241, R242, R248, R250 | 3k | SMD/RF_0805 | ERA6AEB302V | 1%, 125mW, thick film |  |  |  | 1670234 | 4
Top | 6 | C2, C25, C35, C58, C68, C91 | 100uF | SMD/C_1210 | C1210C107M8PACTU | X5R, 10V, 20% |  |  |  | 2442786 | 6
Top | 6 | C8, C21, C41, C54, C74, C87 | 680uF | EEEFK1CxxxGP | EEEFK1C681GP | 16V, 80mR |  |  |  | 2326200 | 6
Top | 6 | P1, P3, P4, P6, P7, P9 | MCX | MCX | MCX6251B1-3GT30G-50 | MCX, straight |  |  |  | 1111323 | 6
Top | 6 | R9, R80, R151, R214, R215, R216 | 470 | SMD/RF_0805 | RC0805FR-07470RL | 1%, 125mW, thick film |  |  |  | 9237445 | 6
Top | 6 | R16, R42, R87, R113, R158, R184 | 25 | TRIMMER 3296W | 3296W-1-250LF | 10%, 500mW, 100ppm/K, 25turn |  |  |  | 2328402 | 6
Top | 6 | R19, R40, R90, R111, R161, R182 | 3k | SMD/RF_0805 | ERA6AEB302V | 0.1%, 125mW, 25ppm/K, thin film |  |  |  | 1670234 | 6
Top | 6 | R28, R31, R99, R102, R170, R173 | 1M | SMD/RF_0805 | RC0805FR-071ML | 1%, 125mW, thick film |  |  |  | 9237992 | 6
Top | 6 | R53, R68, R124, R139, R195, R210 | 560 | SMD/RF_0805 | RC0805FR-07560RL | 1%, 125mW, thick film |  |  |  | 9237461 | 6
Top | 6 | U2, U8, U11, U17, U20, U26 | LM4040-2.5 | TI-DBZ3_N | LM4040AIM3-2.5/NOPB | 2.5V, 0.1%, 20ppm/K |  |  |  | 3009186 | 6
Top | 6 | U3, U7, U12, U16, U21, U25 | ADA4084-1 | SOT-23-OT5_L | ADA4084-1ARJZ-R7 | +-15V, 3.9nV/rtHz |  | 584-ADA4084-1ARJZ-R7 |  |  | 6
Top | 6 | U5, U9, U14, U18, U23, U27 | AD8221ARZ | ADI-R-8_L | AD8221ARZ | +-18V, Vos=60uV |  | 584-AD8221ARZ |  |  | 6
Top | 7 | C13, C15, C46, C48, C79, C81, C100 | 1nF | SMD/C_0805 | 08051A102JAT2A | NP0, 100V, 5% |  |  |  | 1740662 | 7
Top | 8 | D1, D8, D9, D16, D17, D24, D26, D30 | 1PS76SB10 | DIOD-SOD-323-2_V - Cloned | 1PS76SB10,115 | 30V, 200mA |  |  |  | 1081179 | 8
Top | 8 | U4, U6, U13, U15, U22, U24, U28, U29 | LM4040-5 | TI-DBZ3_N | LM4040AIM3-5.0/NOPB | 5V, 0.1%, 30ppm/K |  |  |  | 3124408 | 8
Top | 9 | J1, J2, J3, J4, J5, J6, J7, J8, J9 | Bushing | BUSHING_M4 | 7460307 | M4 |  |  |  | 1821272 | 9
Top | 9 | R22, R37, R57, R93, R108, R128, R164, R179, R199 | 10 | SMD/RF_0805 | CRT0805-BY-10R0ELF | 0.1%, 100mW, 25ppm/K, thin film |  |  |  | 2008313 | 9
Top | 10 | Q12, Q18, Q19, Q37, Q43, Q44, Q62, Q68, Q69, Q80 | BCM56DS | SC74 | BCM56DSX | 80V, 1A, matched |  | 771-BCM56DSX |  |  | 10
Top | 12 | Q24, Q25, Q49, Q50, Q74, Q75, Q81, Q82, Q83, Q84, Q85, Q86 | BSS123L | SOT-23_L | BSS123L | 100V, 170mA |  |  |  | 2575356 | 12
Top | 12 | R2, R3, R48, R49, R73, R74, R119, R120, R144, R145, R190, R191 | 680 | SMD/R_1206 | RC1206FR-07680RL | 1%, 250mW, 100ppm/K, thick film |  |  |  | 9240934 | 12
Top | 12 | R4, R47, R60, R64, R75, R118, R131, R135, R146, R189, R202, R206 | 100 | SMD/RF_0805 | ERA6AEB101V | 0.1%, 125mW, 25ppm/K, thin film |  | 667-ERA-6AEB101V |  |  | 12
Top | 13 | Q3, Q5, Q11, Q28, Q30, Q36, Q53, Q55, Q61, Q76, Q77, Q78, Q79 | BCM53DS | SC74 | BCM53DSX | 80V, 1A, matched |  | 771-BCM53DSX |  |  | 13
Top | 14 | R5, R46, R76, R117, R147, R188, R223, R228, R229, R230, R231, R233, R243, R249 | 100k | SMD/RF_0805 | RC0805FR-07100KL | 1%, 125mW, thick film |  |  |  | 9237879 | 14
Top | 19 | R13, R43, R61, R84, R114, R132, R155, R185, R203, R217, R218, R219, R220, R221, R222, R235, R237, R238, R239 | 1k | SMD/RF_0805 | RC0805FR-071KL | 1%, 125mW, thick film |  |  |  | 9237496 | 19
Top | 22 | D2, D3, D4, D5, D6, D7, D10, D11, D12, D13, D14, D15, D18, D19, D20, D21, D22, D23, D25, D27, D28, D29 | BAV99 | SOT-23_N | BAV99 | 75V, 300mA, 2pF |  |  |  | 3127231 | 22
Top | 22 | Q1, Q2, Q4, Q6, Q7, Q14, Q15, Q26, Q27, Q29, Q31, Q32, Q39, Q40, Q51, Q52, Q54, Q56, Q57, Q64, Q65, Q91 | 50A02CH | CPH3 | 50A02CH-TL-E | 50V, 0.5A, 690MHz |  |  |  | 2845297 | 22
Top | 22 | Q8, Q9, Q16, Q17, Q20, Q21, Q22, Q33, Q34, Q41, Q42, Q45, Q46, Q47, Q58, Q59, Q66, Q67, Q70, Q71, Q72, Q90 | 50C02CH | CPH3 | 50C02CH-TL-E | 50V, 0.5A, 500MHz |  |  |  | 2727939 | 22
Top | 27 | R8, R18, R20, R32, R39, R41, R52, R65, R70, R79, R89, R91, R103, R110, R112, R123, R136, R141, R150, R160, R162, R174, R181, R183, R194, R207, R212 | 200 | SMD/RF_0805 | ERA6AEB201V | 0.1%, 125mW, 25ppm/K, thin film |  | 667-ERA-6AEB201V | P200DACT-ND |  | 27
Top | 39 | R1, R7, R11, R12, R17, R27, R34, R51, R55, R56, R59, R66, R72, R78, R82, R83, R88, R98, R105, R122, R126, R127, R130, R137, R143, R149, R153, R154, R159, R169, R176, R193, R197, R198, R201, R208, R240, R244, R247 | 2R2 | SMD/RF_0805 | RC0805FR-072R2L | 1%, 125mW, thick film |  |  |  | 9237160 | 39
Top | 56 | R6, R14, R15, R21, R23, R24, R25, R26, R33, R35, R36, R38, R44, R45, R50, R62, R71, R77, R85, R86, R92, R94, R95, R96, R97, R104, R106, R107, R109, R115, R116, R121, R133, R142, R148, R156, R157, R163, R165, R166, R167, R168, R175, R177, R178, R180, R186, R187, R192, R204, R213, R224, R225, R232, R234, R236 | 10k | SMD/RF_0805 | RC0805FR-0710KL | 1%, 125mW, thick film |  |  |  | 9237755 | 56
Top | 79 | C1, C3, C4, C5, C6, C7, C9, C10, C11, C12, C16, C17, C18, C19, C20, C22, C23, C24, C26, C27, C28, C30, C31, C32, C33, C34, C36, C37, C38, C39, C40, C42, C43, C44, C45, C49, C50, C51, C52, C53, C55, C56, C57, C59, C60, C61, C63, C64, C65, C66, C67, C69, C70, C71, C72, C73, C75, C76, C77, C78, C82, C83, C84, C85, C86, C88, C89, C90, C92, C93, C94, C96, C97, C98, C99, C101, C102, C105, C106 | 100nF | SMD/C_0805 | 08055C104KAT2A | X7R, 50V, 10% |  |  |  | 499687 | 79
Bottom | 1 | Q88 | D45H11 | TO220 Lars | D45H11 | PNP, TO220, 80V, 10A |  |  |  | 9557164 | 1
Bottom | 1 | Q93 | D44H11 | TO220 Lars | D44H11 | NPN, TO220, 80V, 10A |  |  |  | 1611376 | 1
Bottom | 3 | L1, L2, L3 | 64nH | SLC7530 coilcraft | SLC7530S-640MLC | 123uR, 32A |  | 994-SLC7530S-640MLC |  |  | 3
Bottom | 3 | Q10, Q35, Q60 | IXTH90P10P | TO247Lars | IXTH90P10P | 100V, 90A |  | 747-IXTH90P10P |  |  | 3
Bottom | 3 | Q13, Q38, Q63 | IXTT96N20P | TO247Lars | IXTH96N20P | 200V, 96A | 193-442 |  |  |  | 3
Bottom | 3 | R63, R134, R205 | 5m | SMD/R_2512 | LRMAP2512-R005FT4 | 1%, 3W, 50ppm/K |  |  |  | 2079432 | 3
Bottom | 6 | R10, R54, R81, R125, R152, R196 | 10m | SMD/R_2512 | LRMAP2512-R01FT4 | 1%, 3W, 50ppm/K |  |  |  | 2079429 | 6
Bottom | 6 | RT1, RT2, RT3, RT4, RT5, RT6 | 10k | SMD/R_0805 | NTCS0805E3103HMT | NTC, B=3570 |  |  |  | 3020835 | 6

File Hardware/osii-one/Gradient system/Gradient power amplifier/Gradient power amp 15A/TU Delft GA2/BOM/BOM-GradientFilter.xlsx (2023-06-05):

Quantity | Designator | Value | Pin Info | Footprint | MPN
3 | C1, C5, C9 | 390pF | NP0, 100V, 5% | SMD/C_0805 | 08051A391JAT2A
6 | C2, C3, C6, C7, C10, C11 | 100nF | NP0, 100V, 5% | 1812 | C1812C104J1GACTU
3 | C4, C8, C12 | 3.9nF | NP0, 2kV, 5% | SMD/C_2225 | C2225C392JGGACTU
6 | J1, J2, J3, J4, J5, J6 | MH3.5 | mounting hole | MTHOLE3.5MM_TOPBOT7MM | M3 brass washer
3 | L1, L3, L5 | 15uH | 26A, 2.4mR, 11MHz | WE-HCF 2818 | 7443641500
3 | L2, L4, L6 | 1.2uH | 2.8A, 20mR, 150MHz | WE-TPC-4828-MH | 7440430012
3 | P1, P3, P5 | Header 2 | 2mm hole, 5mm pitch | WireToBoard_H2mm_P5mm
3 | P2, P4, P6 | SCREW-5.0/5.08 2WAYS | 16A, 12-28AWG, 5mm | SCREW-5.0-2WAYS_V | 20020316-G021B01LF
3 | R1, R5, R9 | 22R | 500mW, 1%, anti surge | SMD/RF_0805 | ERJP06F22R0V
3 | R2, R6, R10 | 200R | 1W, 1%, thick film | SMD/R_2512 | CRCW2512200RFKEG
3 | R3, R7, R11 | 47R | 3W, 1%, thick film | SMD/R_2512 | 352247RFT
3 | R4, R8, R12 | 2R2 | 3W, 5%, thick film | SMD/R_2512 | 35222R2JT
PCBs | Farnell | aantal
1 | 2332701 | 3
 | 1679457 | 6
 | 2906248 | 3
 | 1377536 | 1
 | 2431615 | 3
 | 1635845 | 3
 | 1466845 | 3 |  | 12mm standoff M3 Ni plated | 05.13.123
 | 2579786 | 3
 | 1750733 | 3
 | 1470047 | 3
 | 2476456 | 3
 | 2476359 | 3
 | 1419447 | 1 |  | M3 nut zinc plated | M3- HFST-Z100-

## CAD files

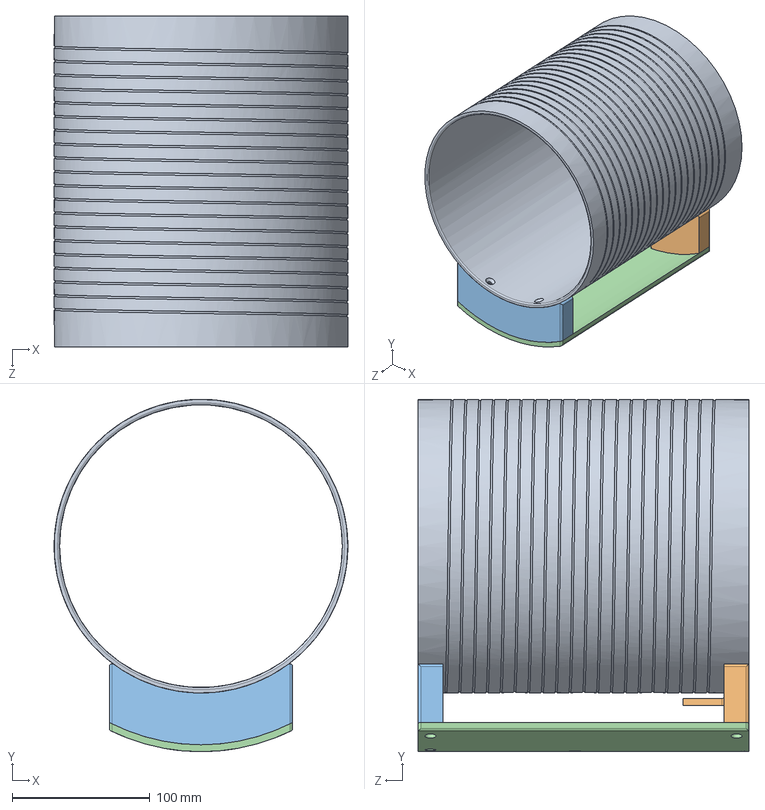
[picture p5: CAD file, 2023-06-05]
Hardware/osii-one/RF system/RF coils/Solenoid d205mm N20 3seg/3D models/Solidworks/RF coil low-field - d205mm - N20_FullCoil.SLDASM
213.0 x 255.5 x 240.0 mm
20 cm long - 20 turns
Back foot
Front foot
Bore bed

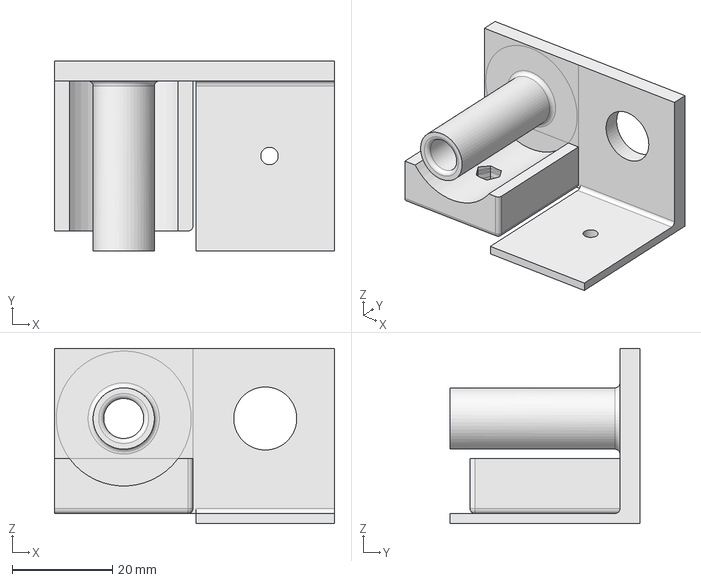
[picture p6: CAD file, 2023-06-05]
Hardware/osii-one/Gradient system/Gradient power amplifier/Gradient power amp 15A/TU Delft GA2/ASSEMBLY/FERRITE HOLDER/FerriteHolder3DPrint_2x.step
56.0 x 38.0 x 35.0 mm

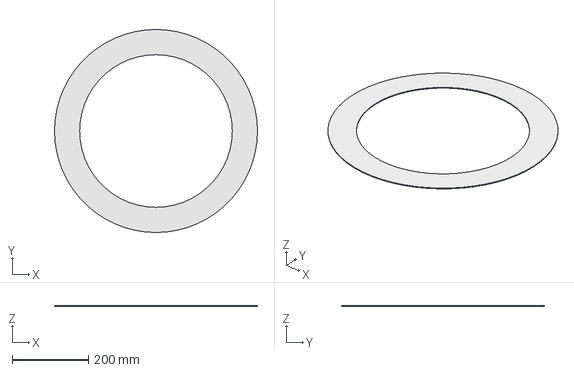
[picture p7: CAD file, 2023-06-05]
Hardware/osii-one/Magnet/30cm Halbach Magnet/FreeCAD/Lids/OSI2ONE_Magnet_v1.0_lid_ring1-5_ring7-10.FCStd
532.0 x 532.0 x 2.00 mm

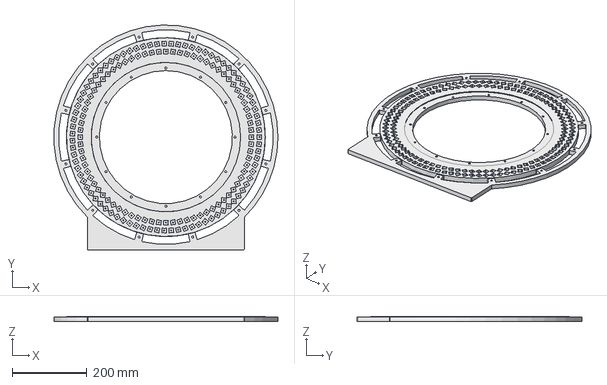
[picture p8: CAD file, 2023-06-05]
Hardware/osii-one/Magnet/30cm Halbach Magnet/FreeCAD/Rings/OSI2ONE_Magnet_v1.0_Ring1.FCStd
599.4 x 601.8 x 14.0 mm

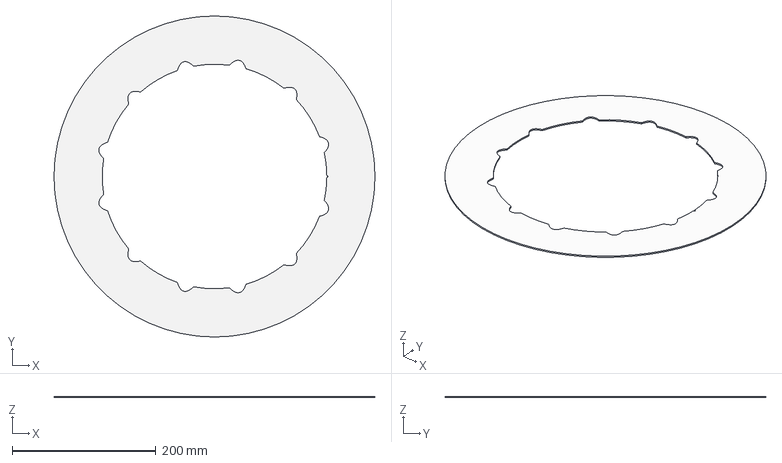
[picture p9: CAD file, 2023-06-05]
Hardware/osii-one/Magnet/30cm Halbach Magnet/Production/Lids/OSI2ONE_Magnet_v1.0_lid_ring11-13-Body.step
446.0 x 446.0 x 2.00 mm

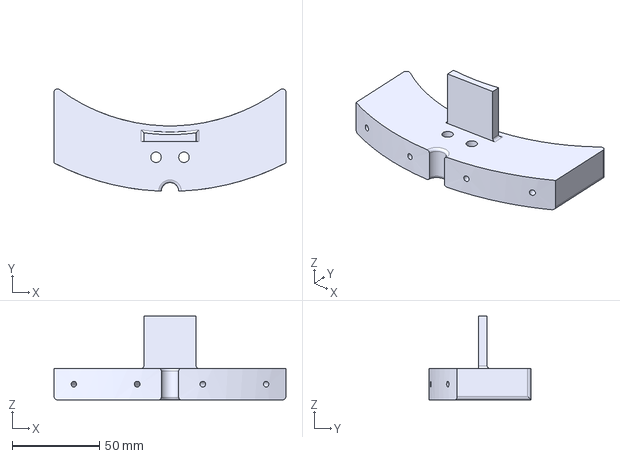
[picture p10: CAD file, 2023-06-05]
Hardware/osii-one/RF system/RF coils/Solenoid d205mm N20 3seg/3D models/STEP/RF coil low-field - d205mm - N20_FootBack.step
133.0 x 58.7 x 48.0 mm

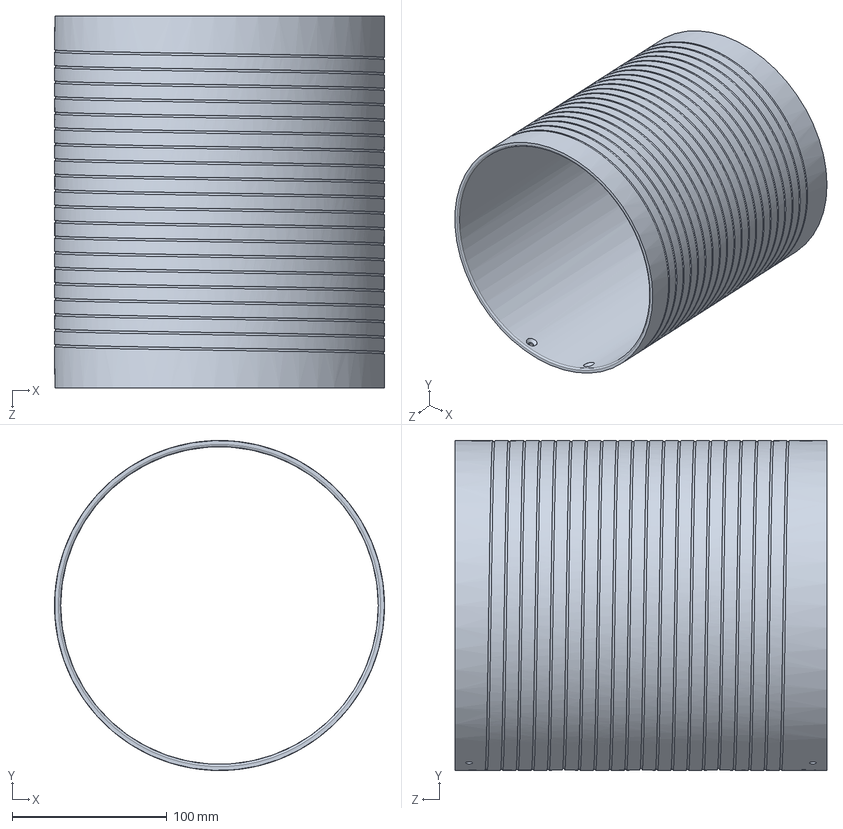
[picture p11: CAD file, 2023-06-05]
Hardware/osii-one/RF system/RF coils/Solenoid d205mm N20 3seg/3D models/Solidworks/RF coil low-field - d205mm - N20_cylinder.SLDPRT
213.0 x 213.0 x 240.0 mm

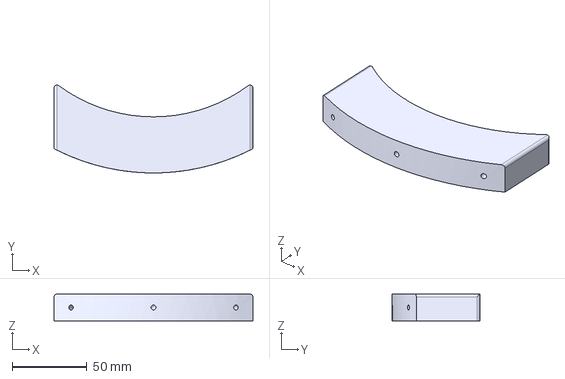
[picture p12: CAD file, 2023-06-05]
Hardware/osii-one/RF system/RF coils/Solenoid d205mm N20 3seg/3D models/STEP/RF coil low-field - d205mm - N20_FootFront.step
133.0 x 58.7 x 18.0 mm

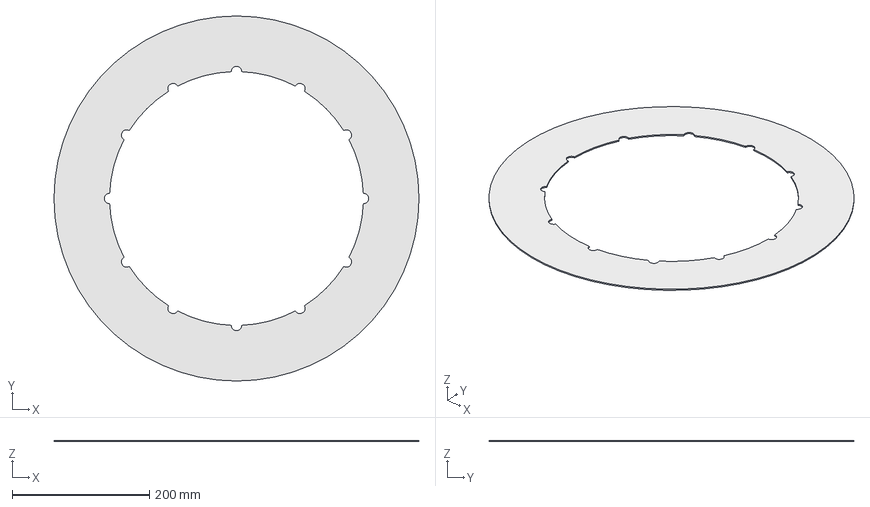
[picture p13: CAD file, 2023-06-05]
Hardware/osii-one/Magnet/30cm Halbach Magnet/FreeCAD/Lids/OSI2ONE_Magnet_v1.0_lid_ring6.FCStd
532.0 x 532.0 x 2.00 mm

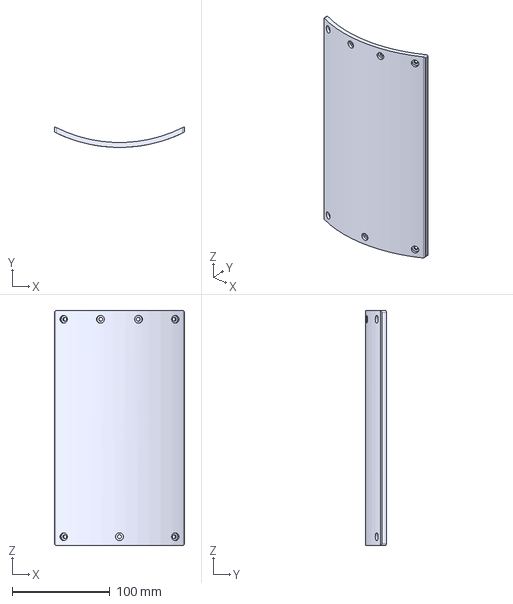
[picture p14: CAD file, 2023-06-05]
Hardware/osii-one/RF system/RF coils/Solenoid d205mm N20 3seg/3D models/STEP/RF coil low-field - d205mm - N20_BoreBed.step
133.0 x 21.3 x 240.0 mm

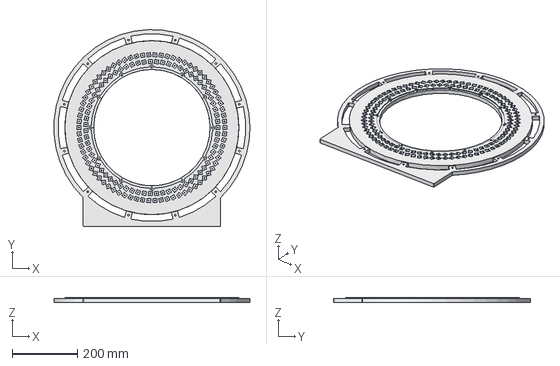
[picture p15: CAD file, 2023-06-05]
Hardware/osii-one/Magnet/30cm Halbach Magnet/FreeCAD/Rings/OSI2ONE_Magnet_v1.0_Ring6.FCStd
599.4 x 601.8 x 14.0 mm

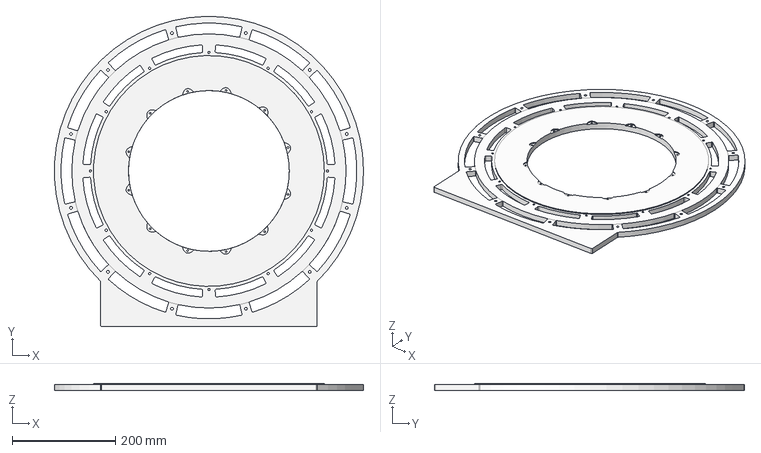
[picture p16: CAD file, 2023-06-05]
Hardware/osii-one/Magnet/30cm Halbach Magnet/FreeCAD/Rings/OSI2ONE_Magnet_v1.0_Template_Ring11-13.step
599.7 x 601.9 x 14.0 mm

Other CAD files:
Hardware/osii-one/Magnet/30cm Halbach Magnet/Complete System STL/OSI2ONE_Magnet_v1.0_complete.stl
Hardware/osii-one/Magnet/30cm Halbach Magnet/FreeCAD/Lids/OSI2ONE_Magnet_v1.0_lid_ring11-13.FCStd
Hardware/osii-one/Magnet/30cm Halbach Magnet/FreeCAD/Rings/OSI2ONE_Magnet_v1.0_Ring8.FCStd
Hardware/osii-one/Magnet/30cm Halbach Magnet/Production/Lids/OSI2ONE_Magnet_v1.0_lid_ring1-5_ring7-10.step
Hardware/osii-one/Magnet/30cm Halbach Magnet/FreeCAD/Rings/OSI2ONE_Magnet_v1.0_Ring7.FCStd
Hardware/osii-one/Magnet/30cm Halbach Magnet/Production/Lids/OSI2ONE_Magnet_v1.0_lid_ring6.step
Hardware/osii-one/Magnet/30cm Halbach Magnet/FreeCAD/Rings/OSI2ONE_Magnet_v1.0_Ring10.FCStd
Hardware/osii-one/Magnet/30cm Halbach Magnet/FreeCAD/Rings/OSI2ONE_Magnet_v1.0_Ring2.FCStd
Hardware/osii-one/Magnet/30cm Halbach Magnet/FreeCAD/Rings/OSI2ONE_Magnet_v1.0_Ring3andRing5.FCStd
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

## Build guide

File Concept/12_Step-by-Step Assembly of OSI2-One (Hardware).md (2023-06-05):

<h1>Constructing the OSI<sup>2</sup> One MRI Imager</h1>

<h2>Current Methology</h2>

While the designs are all here, it is important to know how the components all go together to form an open-source MRI machine. Furthermore, it is important to know how to test and optimize your build for further development.

<h2>Parts List</h2>

<ul>
<li><b>30cm Halbach Magnet</b>:  Used to generate a strong and uniform magnetic field to facilitate the imaging process by manipulating the alignment of hydrogen nuclei.<p>Description: This part needs to be 3D Printed or CNC'd to exact specifications, incorporating over 4,000 permanent magnets (~4000x (12x12x12)mm³ NdFeB magnets in Halbach arrangement!</p></li>
<li><b>Solenoid d205mm N20 3seg</b>: generate a focused and uniform RF magnetic field in the region of interest, ensuring efficient excitation and detection of the signals from the targeted area. <p>Description: This part needs to be 3D printed or CNC'd to exact specifications. The magnetic field is both created by and read back using this coil.</p></li>
<li><b>More to come...</b></li>
</ul>

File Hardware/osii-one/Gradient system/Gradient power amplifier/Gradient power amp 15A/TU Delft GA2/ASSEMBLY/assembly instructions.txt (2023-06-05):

Mounting torque 0.75Nm heatsink etc.  //  power supply strips 1Nm // Elco's 1.2Nm
Use brass screws for the power strips to reduce the contact resistance

back panel screws M2.5 x 10  with Schroff 21100464
front panel screws Schroff 21100464 + 21101101
bottom to rods M3 x 6 cheese
bottom to 3D printed ferrite holder M3 x 10 sunk and M3 nuts in the printed parts
bottom to relays M3 x 10 sunk
bottom to heatsink M3 x 6 sunk
bottom to capacitor holders M3 x 10 sunk
PCB to power strips M4 x 8 inbus. Use 2mm aluminium spacer rings on the bushings
PCB to capacitor (2x) M5 x 10 philips

power strip to power strip M4 x 8
PCB to plastic spacer on heatsink M3 x 6 cheese use plastic washer on top of PCB for insulation
GND bracket to GND strip and side panel M4 x 8
GND plate to capacitor M5 x 10
DC in connector M3 x 12 black

thermalgrease should not create a conducting path between the heatspreader plate and the heatsink
use thermal grease between the NTCs and the FET package for thermal contact

The Gradient Filter can be mounted on the back of the amplifier on the 12mm standoffs that connect
the GND of the PCB to the enclosure. Solid copper wires can be used to connect P1,3,5 to the
X, Y and Z outputs of the amplifier.

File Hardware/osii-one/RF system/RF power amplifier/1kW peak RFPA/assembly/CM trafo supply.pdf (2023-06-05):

Ribbon cable n=10
3x through each core

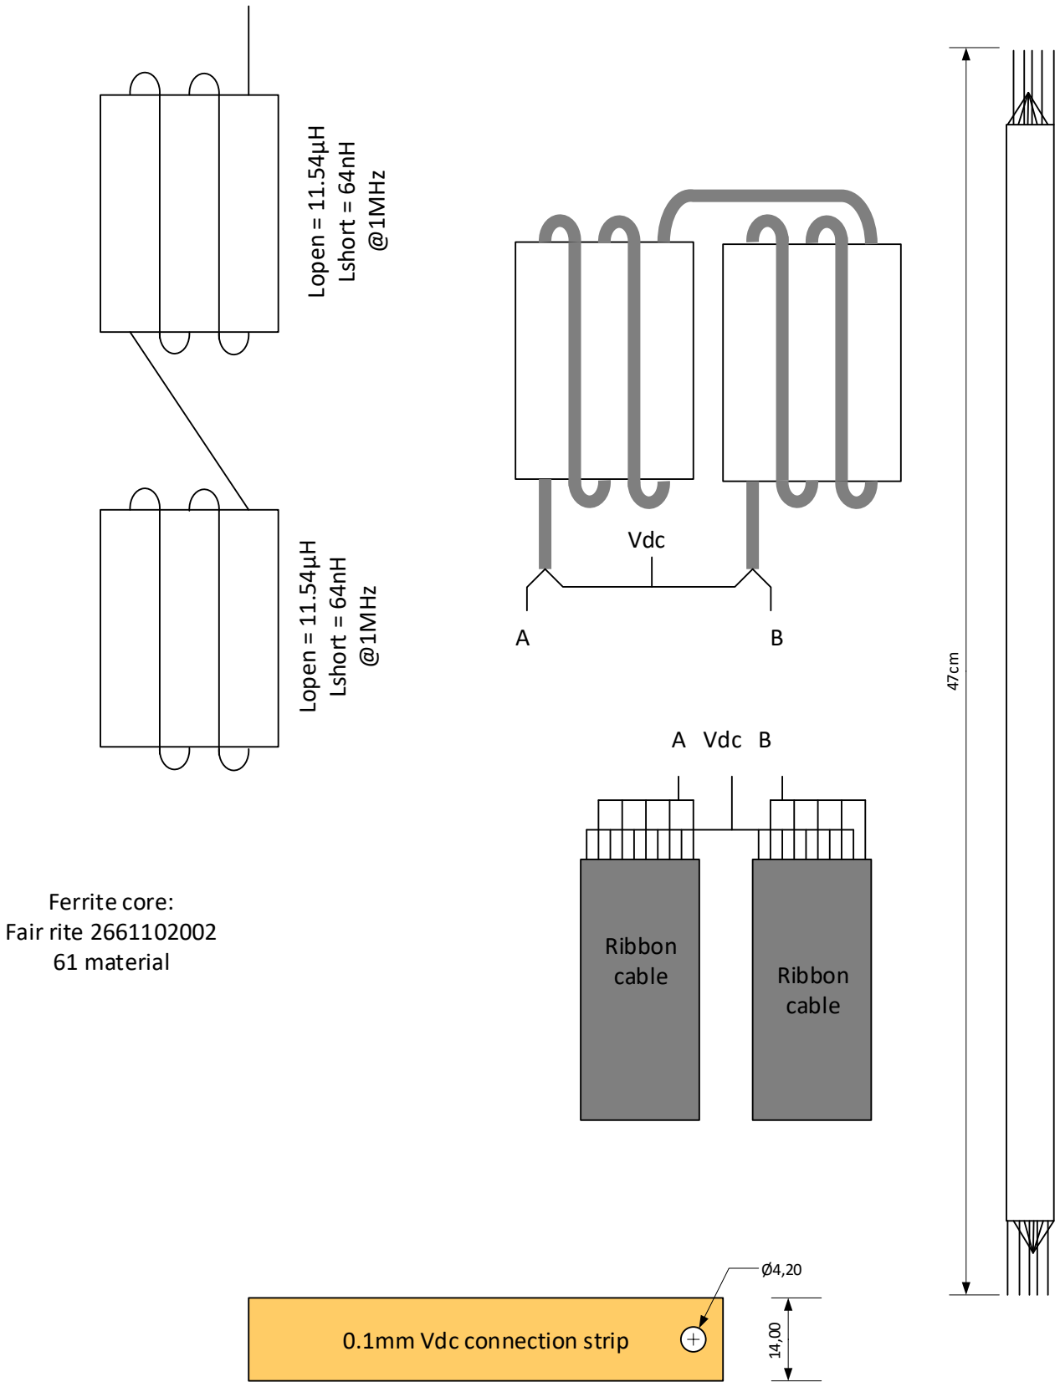
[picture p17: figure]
Vdc; Ribbon; cable; A Vdc B; 0.1mm Vdc connection strip; Ferrite core: Fair rite 2661102002 61 material; Lopen = 11.54µH; Lshort = 64nH; @1MHz

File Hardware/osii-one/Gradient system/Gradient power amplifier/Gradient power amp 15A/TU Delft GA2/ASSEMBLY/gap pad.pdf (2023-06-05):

50

50

3x gap pad. Copy holes from aluminium heat spreader

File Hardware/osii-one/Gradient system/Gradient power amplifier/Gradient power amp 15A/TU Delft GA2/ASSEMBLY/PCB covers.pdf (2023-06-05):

X | Y | Z

Covers for over the PCB to limit thermal fluctuations for extra stable operation.

Print at 100% scaling. The dimensions should be 50mmx40mm

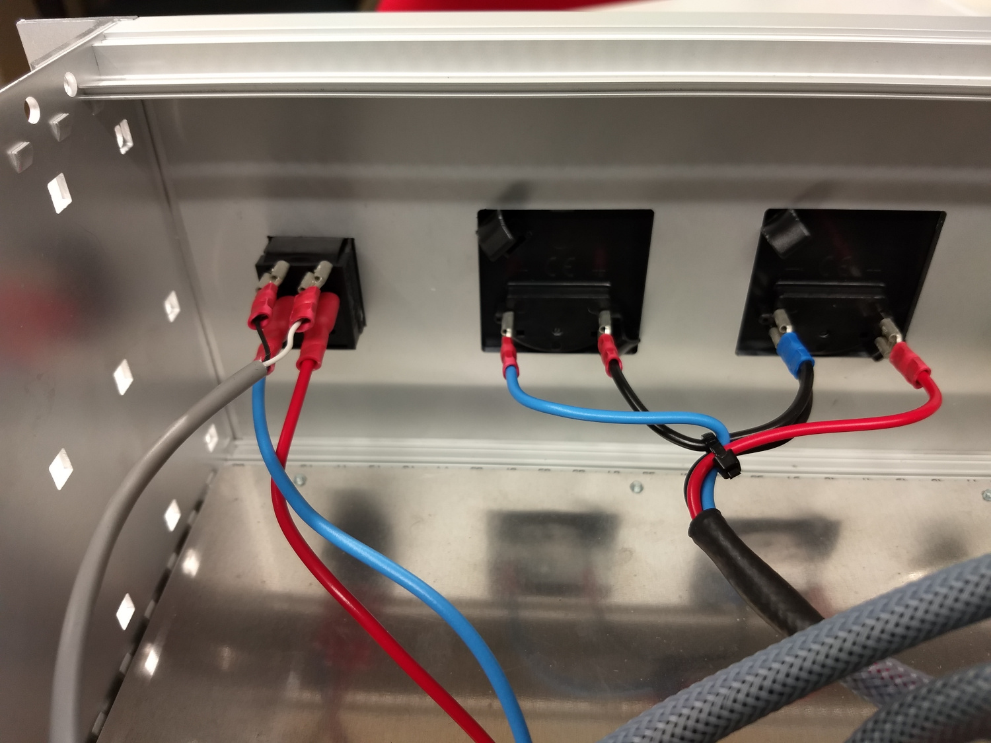
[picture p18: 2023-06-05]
Hardware/osii-one/Gradient system/Gradient power amplifier/Gradient power amp 15A/TU Delft GA2/ASSEMBLY/PICTURES/PowerSwitch.jpg

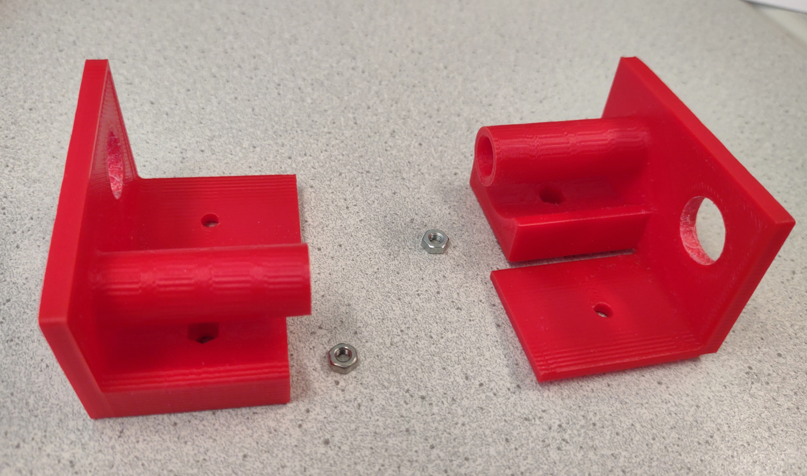
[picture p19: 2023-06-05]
Hardware/osii-one/Gradient system/Gradient power amplifier/Gradient power amp 15A/TU Delft GA2/ASSEMBLY/PICTURES/FerriteHolderNuts.jpg

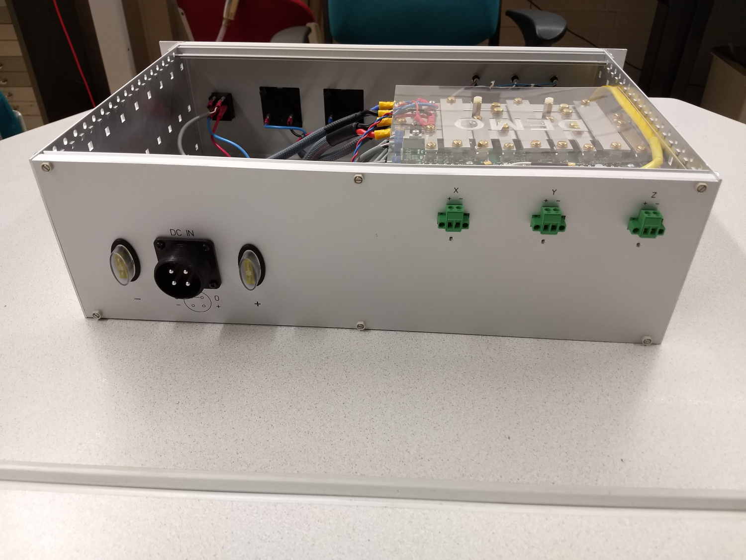
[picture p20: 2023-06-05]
Hardware/osii-one/Gradient system/Gradient power amplifier/Gradient power amp 15A/TU Delft GA2/ASSEMBLY/PICTURES/AssembledBack.jpg

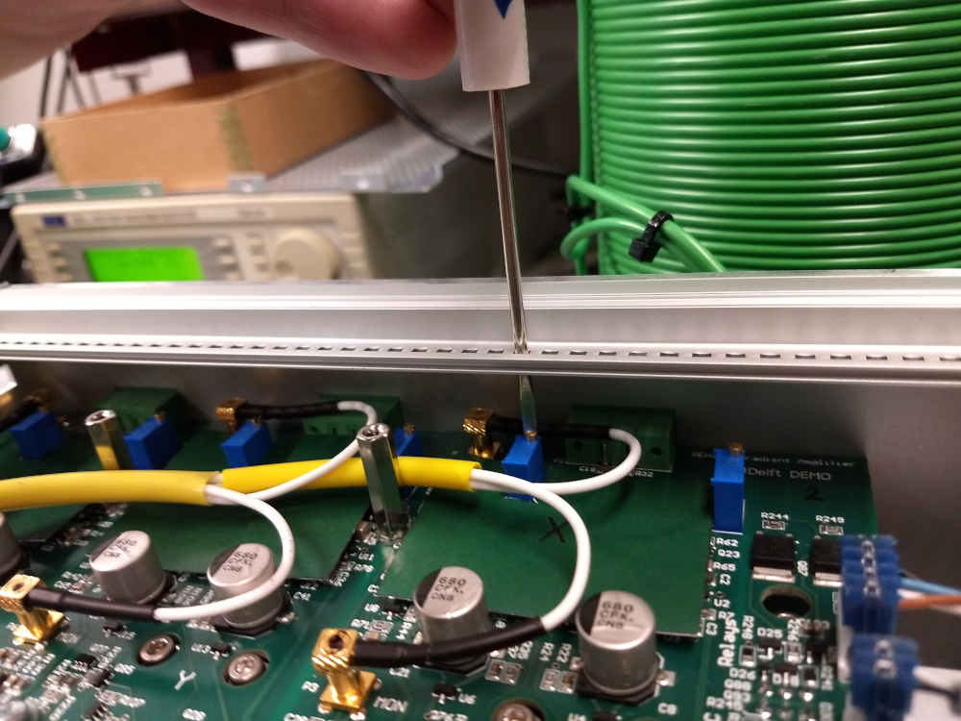
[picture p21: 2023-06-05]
Hardware/osii-one/Gradient system/Gradient power amplifier/Gradient power amp 15A/TU Delft GA2/ASSEMBLY/PICTURES/BiasPotentiometers.jpg

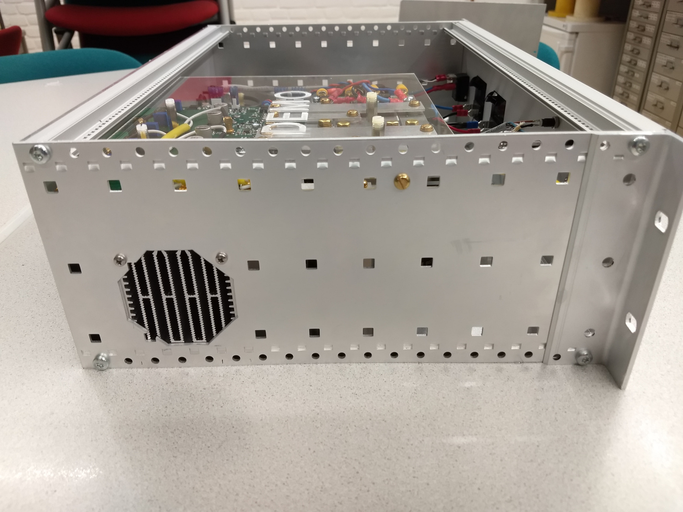
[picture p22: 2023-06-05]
Hardware/osii-one/Gradient system/Gradient power amplifier/Gradient power amp 15A/TU Delft GA2/ASSEMBLY/PICTURES/AssembeldLeft.jpg

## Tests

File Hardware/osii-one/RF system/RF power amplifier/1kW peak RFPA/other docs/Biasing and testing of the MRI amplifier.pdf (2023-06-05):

Biasing and testing of the MRI amplifier

- Before connecting the Lascar power supply adjust its voltages to 8V, -5V and +5V
- Turn the Phoenix voltage adjustment potentiometer to its lowest setting
- Connect a 50Ω/100W..1kW load to the output of the amplifier.
- Turn VR1 and VR2 counter clockwise until it clicks
- Connect P1 and switch on the power, the LOW voltage indicator LED will be on
- Increase the voltage of the Phoenix power supply to about 34V
- Increase the voltage at VR1,2 to 2.0V. This can be measured at R14 and R17.
- Press the Output ON button on the front of the amplifier to enable the amplifier.
- Apply a 10mV signal of 1MHz at the RF In input.
- Apply a single pulse with a pulse time of 10µs and a level of 1.5..5V at the Enable input and check if a signal is present at the load resistor and see if the voltage at J3 switches on and off.
- Increase the voltage out of the phoenix power supply to 56V and the bias voltage potentiometers to 2.5V.
- Test with 250mV amplitude input signal while checking the sine wave at the load with single enable pulses.
- Slowly increase the input signal amplitude and see if the peaks of the sine wave become distorted. The maximum output signal is 632Vpp at 1.1Vpp input signal. Increase the bias voltage to just the value at which the signal looks undistorted at full power (1kW). This takes a bias voltage of around 2.7V. Make sure that both potentiometers are set to the same voltage while tuning before applying an enable pulse.

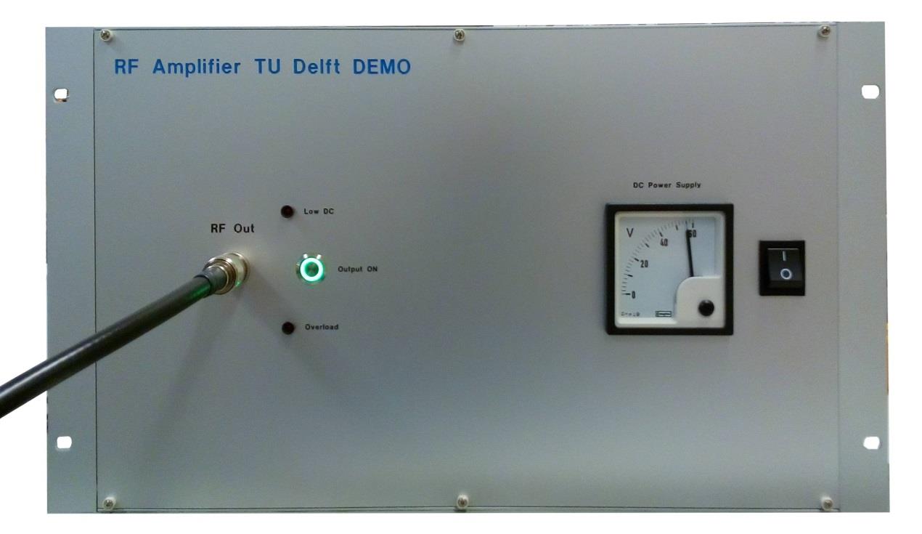
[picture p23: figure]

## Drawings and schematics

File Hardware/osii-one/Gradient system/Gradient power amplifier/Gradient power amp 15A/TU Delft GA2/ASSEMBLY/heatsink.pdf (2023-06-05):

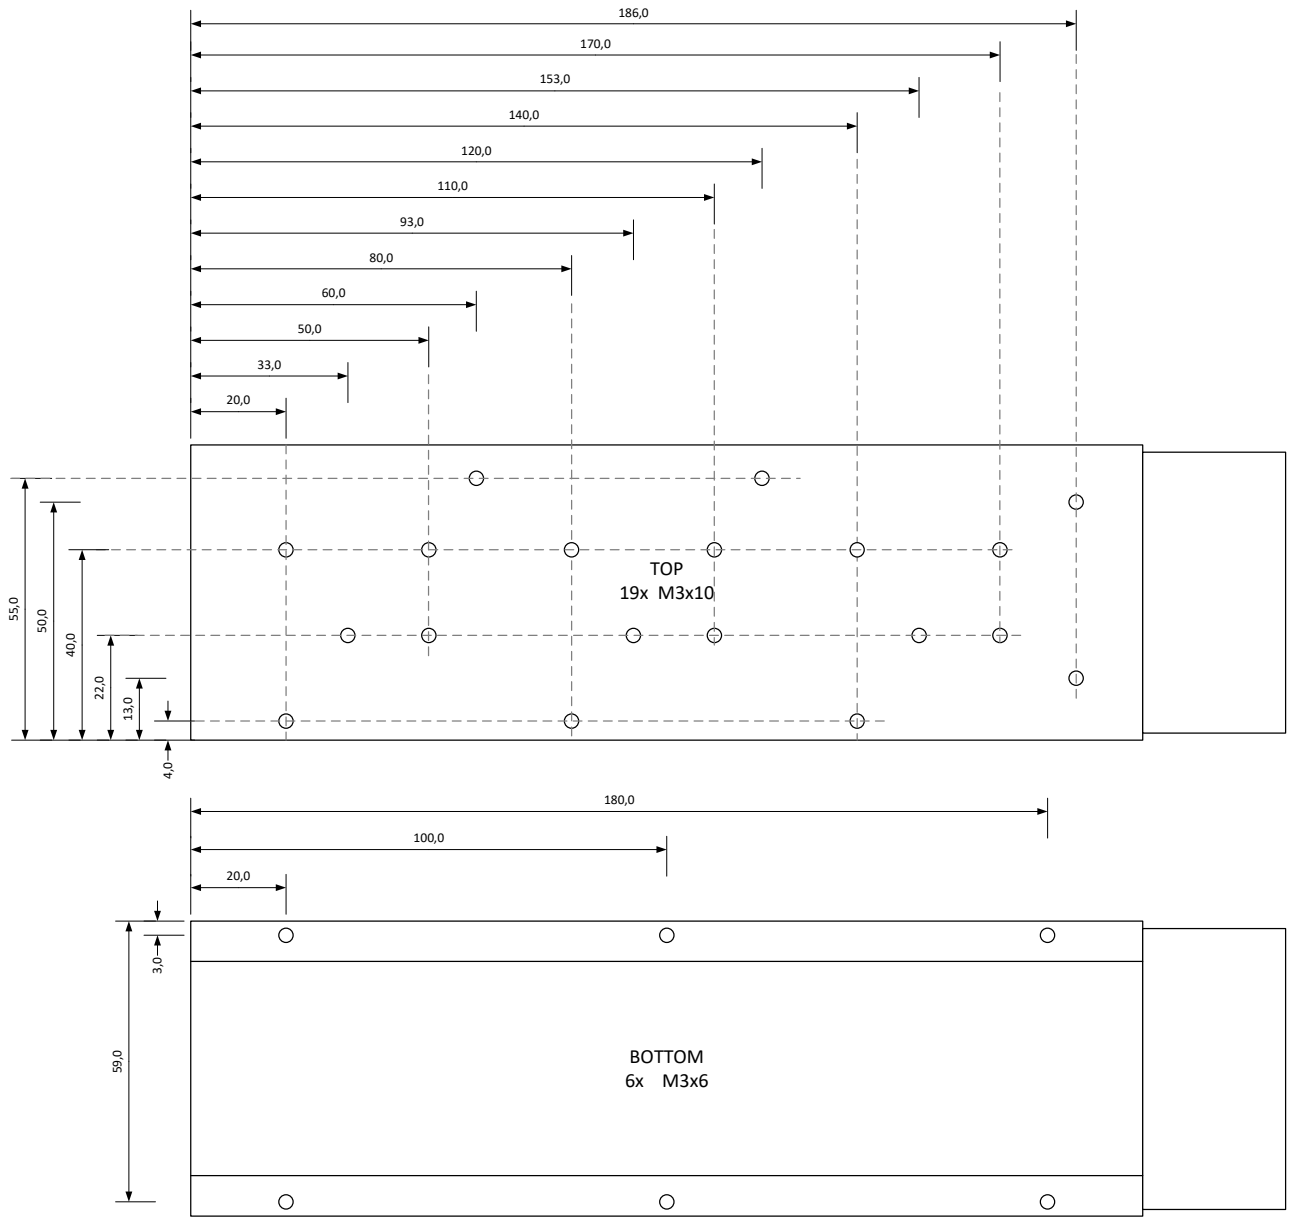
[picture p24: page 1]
TOP; BOTTOM

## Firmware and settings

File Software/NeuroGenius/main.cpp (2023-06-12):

#include <tchar.h>
#include <windows.h>

/*  Declare Windows procedure  */
LRESULT CALLBACK WindowProcedure (HWND, UINT, WPARAM, LPARAM);

/*  Make the class name into a global variable  */
TCHAR szClassName[ ] = _T("NeuroGeniusApp");

int WINAPI WinMain (HINSTANCE hThisInstance,
                     HINSTANCE hPrevInstance,
                     LPSTR lpszArgument,
                     int nCmdShow)
{
    HWND hwnd;
    MSG messages;
    WNDCLASSEX wincl;
    HMENU hMenu, hSubMenuFile, hSubMenuEdit, hSubMenuData, hSubMenuProject, hSubMenuMRImaging, hSubMenuHelp;

    /* Create the menu */
    hMenu = CreateMenu();

    /* Add 'File' menu */
    hSubMenuFile = CreatePopupMenu();
    AppendMenu(hSubMenuFile, MF_STRING, 1, _T("Open..."));
    AppendMenu(hSubMenuFile, MF_STRING, 2, _T("Save"));
    AppendMenu(hSubMenuFile, MF_SEPARATOR, 0, NULL);
    AppendMenu(hSubMenuFile, MF_STRING, 3, _T("Exit"));
    AppendMenu(hMenu, MF_STRING | MF_POPUP, (UINT)hSubMenuFile, _T("File"));

    // Similarly, add the remaining menu and submenu items
    // Edit, Data, Project, MR Imaging, Help

    /* Register the window class, and if it fails quit the program */
    wincl.hInstance = hThisInstance;
    wincl.lpszClassName = szClassName;
    wincl.lpfnWndProc = WindowProcedure;
    wincl.style = CS_DBLCLKS;
    wincl.cbSize = sizeof (WNDCLASSEX);
    wincl.hIcon = LoadIcon (NULL, IDI_APPLICATION);
    wincl.hIconSm = LoadIcon (NULL, IDI_APPLICATION);
    wincl.hCursor = LoadCursor (NULL, IDC_ARROW);
    wincl.lpszMenuName = NULL;
    wincl.cbClsExtra = 0;
    wincl.cbWndExtra = 0;
    wincl.hbrBackground = (HBRUSH) COLOR_BACKGROUND;

    if (!RegisterClassEx (&wincl))
        return 0;

    hwnd = CreateWindowEx (
           0,
           szClassName,
           _T("NeuroGenius MR Image Acquisition & Development Project"),
           WS_OVERLAPPEDWINDOW,
           CW_USEDEFAULT,
           CW_USEDEFAULT,
           544,
           375,
           HWND_DESKTOP,
           hMenu, // set menu to the window
           hThisInstance,
           NULL
           );

    ShowWindow (hwnd, nCmdShow);

    while (GetMessage (&messages, NULL, 0, 0))
    {
        TranslateMessage(&messages);
        DispatchMessage(&messages);
    }

    return messages.wParam;
}

LRESULT CALLBACK WindowProcedure (HWND hwnd, UINT message, WPARAM wParam, LPARAM lParam)
{
    switch (message)
    {
        case WM_COMMAND:
            // Handle menu selections here, using wParam to identify the selected menu item
            break;
        case WM_DESTROY:
            PostQuitMessage (0);
            break;
        default:
            return DefWindowProc (hwnd, message, wParam, lParam);
    }
    return 0;
}

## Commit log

2023-06-05 Initial commit
    Removed magnet temporarily
    [BOM behuizing.xlsx, BOM enclosure.xlsx, BOM-GradientAmp2 suppliers.xlsx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]
2023-06-05 30cm halbach magnet upload
    [OSI2ONE_Magnet_v1.0_Ring1.FCStd, OSI2ONE_Magnet_v1.0_Ring10.FCStd, OSI2ONE_Magnet_v1.0_Ring2.FCStd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]
2023-06-07 Adding resources for harvesting liquid nitrogen from the atmosphere and creating superconductive magnets.
